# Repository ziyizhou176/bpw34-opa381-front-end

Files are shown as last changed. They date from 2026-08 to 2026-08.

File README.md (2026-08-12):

# BPW34 + OPA381 Weak-Signal Photodetector Front-End

KiCad-based, version-controlled redesign of a weak optical signal front-end for physics competition work.

## Final V2 design target

- Photodiode: BPW34
- TIA: OPA381
- Supply input: +5 V
- Analog rail: LP5907-3.3 -> AVDD_3V3
- Reference: REF3312 -> VREF_RAW -> 10 kΩ -> VBIAS_1V25, with local 1 µF bypass
- TIA feedback: 1 MΩ || 15 pF
- ADC isolation/filter: 1 kΩ series + 33 nF to AGND
- Calibration injection: CAL_IN -> 100 MΩ -> normally-open SJCAL -> SUM
- MCU interface: +5V_IN / AGND / ADC_OUT to existing STM32G431 board
- Target modulation/detection: 1 kHz optical modulation, 20 kS/s ADC, digital lock-in / FFT in MCU

## Development policy

This repository replaces GUI-only iterative PCB editing. Every electrical/layout milestone must be committed so that schematic, PCB, and production data can be diffed and rolled back.

Planned milestones:

1. `v0.1-schematic` — clean KiCad schematic, ERC pass, footprint mapping reviewed
2. `v0.2-placement` — critical analog placement frozen
3. `v0.3-critical-routing` — SUM, feedback, VBIAS, OPA381 local decoupling completed
4. `v0.4-full-routing` — remaining power/ADC/CAL routing and ground strategy completed
5. `v1.0-production` — DRC pass, Gerber/BOM/PnP ready for fabrication

## Reference design

Layout principles will be compared against the open hardware project `TU-Darmstadt-APQ/PDH_photodiode`, especially its photodiode/TIA placement, feedback-loop minimization, local decoupling, and ground strategy. The final circuit here is not intended to be an electrical clone; it is redesigned around BPW34, OPA381, 3.3 V single-supply operation, 1.25 V bias, STM32 ADC interfacing, and the calibration network used in this project.

## Status

Repository initialized. Next step: freeze the V2 electrical specification and create the KiCad project skeleton before any PCB routing.

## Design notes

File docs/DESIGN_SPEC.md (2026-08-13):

# Final V2 Electrical Design Specification

This document is the frozen electrical baseline for the KiCad redesign. PCB layout must conform to this specification unless a later commit explicitly changes it.

## 1. System purpose

Weak optical signal measurement front-end for an STM32G431-based instrument. The optical source is expected to be modulated at 1 kHz; the MCU samples at 20 kS/s and performs digital phase-sensitive/FFT processing.

## 2. External interface

### J1 — MCU / supply interface

| Pin | Net | Function |
|---|---|---|
| 1 | +5V_IN | Raw +5 V input |
| 2 | AGND | Analog ground |
| 3 | ADC_OUT | Analog output to STM32 ADC |

### J2 — calibration input

| Pin | Net | Function |
|---|---|---|
| 1 | CAL_IN | External calibration voltage |
| 2 | AGND | Calibration return |

### Production connector freeze

- J1: JST `S3B-PH-SM4-TB(LF)(SN)`, LCSC `C265101`, 3-pin PH 2.0 mm, right-angle SMD.
- J2: JST `S2B-PH-SM4-TB(LF)(SN)`, LCSC `C295747`, 2-pin PH 2.0 mm, right-angle SMD.
- Both connectors are side-entry/right-angle; their mating sides must face the outside of the PCB.
- Placement must follow the Pin 1 / circuit-number marker. Do not describe pin order using only “left” or “right”.
- Minimum courtyard is approximately 11.2 mm x 10.2 mm for J1 and 9.2 mm x 10.2 mm for J2.

## 3. Power chain

- `+5V_IN -> FB1 -> +5V_FILTER`
- `FB1 = BLM18AG601SN1D`, 600 Ω @ 100 MHz
- `U1 = LP5907MFX-3.3/NOPB`
- U1 pin mapping:
  - Pin 1 IN -> +5V_FILTER
  - Pin 2 GND -> AGND
  - Pin 3 EN -> +5V_FILTER
  - Pin 4 NC
  - Pin 5 OUT -> AVDD_3V3

Decoupling:

- C1 = 4.7 µF, +5V_IN to AGND
- C2 = 100 nF, +5V_IN to AGND
- C3 = 4.7 µF, +5V_FILTER to AGND
- C4 = 100 nF, +5V_FILTER to AGND
- C5 = 4.7 µF, AVDD_3V3 to AGND
- C6 = 100 nF, AVDD_3V3 to AGND

## 4. Reference and bias

- `U2 = REF3312AIDBZR`
- U2 pin mapping:
  - Pin 1 IN -> AVDD_3V3
  - Pin 2 OUT -> VREF_RAW
  - Pin 3 GND -> AGND
- C7 = 100 nF, AVDD_3V3 to AGND
- C8 = 1 µF, VREF_RAW to AGND
- R1 = 10 kΩ, 0.1%, `VREF_RAW -> VBIAS_1V25`
- C9 = 1 µF, `VBIAS_1V25 -> AGND`

Nominal bias target: approximately 1.25 V.

## 5. Photodiode and TIA

### D1 — BPW34

- Pin 1 / Anode -> AGND
- Pin 2 / Cathode -> SUM

### U3 — OPA381AIDGKR

Pin mapping:

| Pin | Function | Net |
|---|---|---|
| 1 | NC | NC |
| 2 | -IN | SUM |
| 3 | +IN | VBIAS_1V25 |
| 4 | V- | AGND |
| 5 | NC | NC |
| 6 | OUT | TIA_OUT |
| 7 | V+ | AVDD_3V3 |
| 8 | NC | NC |

Local decoupling:

- C10 = 100 nF, AVDD_3V3 to AGND, placed immediately adjacent to U3 supply pins
- C11 = 1 µF, AVDD_3V3 to AGND, local bulk decoupling

Feedback:

- RF1 = 1 MΩ, 0.1%, SUM to TIA_OUT
- CF1 = 15 pF, C0G, SUM to TIA_OUT
- Exactly one feedback branch; no gain-switch network on the Final V2 board

## 6. ADC output filter

- R2 = 1 kΩ, 0.1%, `TIA_OUT -> ADC_OUT`
- C12 = 33 nF, `ADC_OUT -> AGND`
- Target RC corner is approximately 4.8 kHz

## 7. Calibration network

- KiCad implementation reference mapping:
  - Functional name RCAL -> KiCad reference R3. R3 remains the 100 MΩ calibration resistor.
  - Functional name SJCAL -> KiCad reference SJ1. SJ1 remains the normally-open SJCAL jumper.
  - Functional name TP_CAL -> KiCad reference TP10. TP10 remains the CAL_IN calibration test point.
  - PCB silkscreen may retain the functional labels `SJCAL`, `OPEN`, and `TP_CAL`.
- TP_CAL -> CAL_IN
- RCAL = 100 MΩ, 1%, `CAL_IN -> CAL_R_NODE`
- SJCAL normally open:
  - Pad 1 -> CAL_R_NODE
  - Pad 2 -> SUM
- When SJCAL is closed:
  - `I_CAL = (V_CAL - VBIAS) / RCAL`
- CAL_IN and RCAL must remain electrically isolated from SUM while SJCAL is open

## 8. Test points

| Ref | Net | Nominal pad size |
|---|---|---|
| TP1 | +5V_IN | 1.0 mm |
| TP2 | +5V_FILTER | 1.0 mm |
| TP3 | AVDD_3V3 | 1.0 mm |
| TP4 | VREF_RAW | 1.0 mm |
| TP5 | VBIAS_1V25 | 1.0 mm |
| TP6 | SUM | 0.8 mm |
| TP7 | TIA_OUT | 1.2 mm |
| TP8 | ADC_OUT | 1.2 mm |
| TP9 | AGND | 1.2 mm |
| TP_CAL | CAL_IN | 1.0 mm |

TP6 silkscreen: `SUM_HIZ`.

## 9. PCB constraints

- 2 layers
- 45 mm x 30 mm nominal board size
- 1.6 mm FR-4
- 1 oz copper
- SUM is the highest-priority sensitive node
- D1, U3, RF1 and CF1 form one compact analog cluster
- Minimize SUM copper area and parasitic capacitance
- Keep ADC_OUT, CAL_IN and long AGND current paths away from SUM
- RF1 and CF1 must be physically adjacent to U3
- C10 must form the smallest practical U3 supply-decoupling loop
- Bottom layer should preferably provide a continuous AGND reference plane except where intentionally excluded around the SUM high-impedance region
- VBIAS guard geometry may be used around SUM if it can be implemented without increasing SUM capacitance or compromising routing

## 10. Production intent

Target fabrication/assembly route: JLCPCB / JLCEDA-compatible manufacturing output derived from KiCad Gerber, drill, BOM and pick-and-place files.

## 11. Reference-project policy

The TU Darmstadt `PDH_photodiode` project is used only as an engineering/layout reference. Its wideband ±5 V circuit, different photodiode, amplifier and gain are not copied electrically. Final V2 remains a 3.3 V single-supply OPA381/BPW34 design described by this specification.

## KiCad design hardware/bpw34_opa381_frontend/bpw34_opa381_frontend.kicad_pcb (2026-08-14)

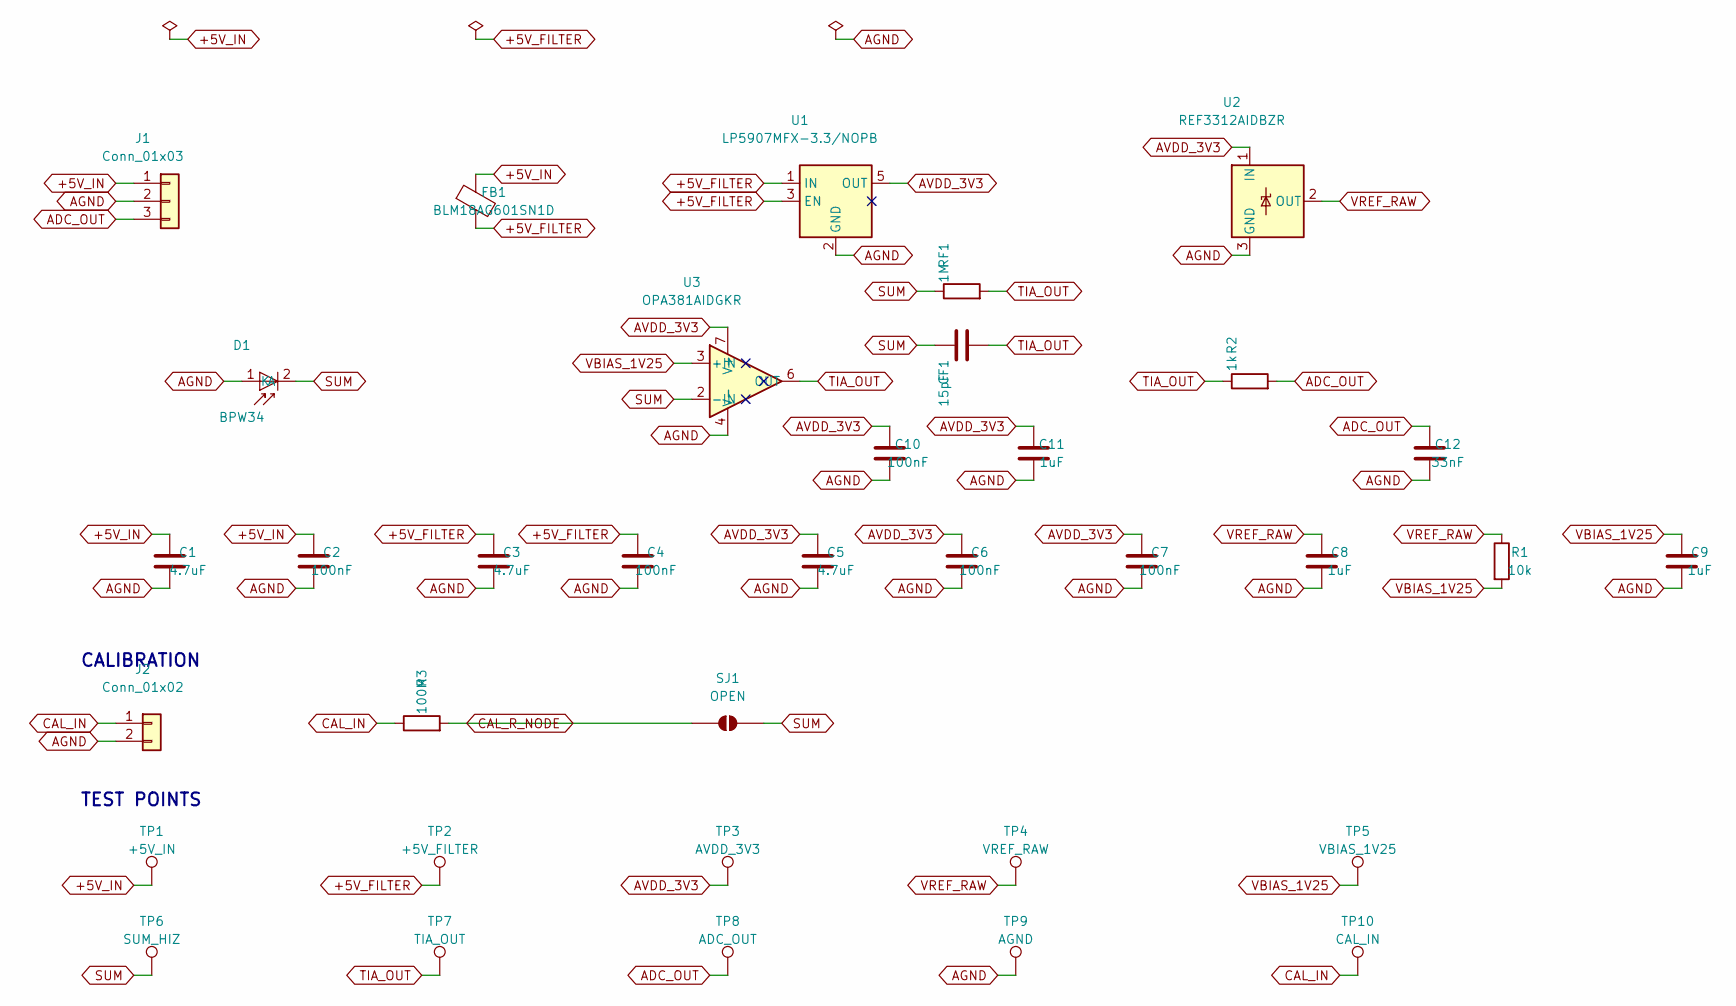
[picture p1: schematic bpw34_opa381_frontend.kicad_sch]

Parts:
C1, C3, C5: 4.7uF; C_0603_1608Metric; MPN GRM188Z71C475KE21D; LCSC C389010
C2, C4, C6, C7, C10: 100nF; C_0603_1608Metric; MPN CL10B104KO8NNNC; LCSC C66501
C8, C9, C11: 1uF; C_0603_1608Metric; MPN 0603B105K160CT; LCSC C108463
C12: 33nF; C_0603_1608Metric; MPN CL10B333KB8NNNC; LCSC C21117
CF1: 15pF; C_0603_1608Metric; MPN CL10C150JB8NNNC; LCSC C1644
D1: BPW34; BPW34_Vishay_P5.10mm; MPN BPW34; LCSC C85128
FB1: BLM18AG601SN1D; L_0603_1608Metric; MPN BLM18AG601SN1D; LCSC C19330
J1: Conn_01x03; JST_PH_S3B-PH-SM4-TB_1x03-1MP_P2.00mm_Horizontal; MPN S3B-PH-SM4-TB(LF)(SN); LCSC C265101
J2: Conn_01x02; JST_PH_S2B-PH-SM4-TB_1x02-1MP_P2.00mm_Horizontal; MPN S2B-PH-SM4-TB(LF)(SN); LCSC C295747
R1: 10k; R_0603_1608Metric; Tolerance 0.1%; MPN RT0603BRD0710KL; LCSC C95204
R2: 1k; R_1206_3216Metric; Tolerance 0.1%; MPN RT1206BRD071KL; LCSC C706405
R3: 100M; R_1206_3216Metric; Tolerance 1%; MPN 1206W4F1006T5E; LCSC C59781
RF1: 1M; R_1206_3216Metric; Tolerance 0.1%; MPN RT1206BRD071ML; LCSC C309662
SJ1: OPEN; SolderJumper-2_P1.3mm_Open_RoundedPad1.0x1.5mm
TP1: +5V_IN; TestPoint_Pad_D1.0mm
TP2: +5V_FILTER; TestPoint_Pad_D1.0mm
TP3: AVDD_3V3; TestPoint_Pad_D1.0mm
TP4: VREF_RAW; TestPoint_Pad_D1.0mm
TP5: VBIAS_1V25; TestPoint_Pad_D1.0mm
TP6: SUM_HIZ; TestPoint_Pad_D0.8mm
TP7: TIA_OUT; TestPoint_Pad_D1.2mm
TP8: ADC_OUT; TestPoint_Pad_D1.2mm
TP9: AGND; TestPoint_Pad_D1.2mm
TP10: CAL_IN; TestPoint_Pad_D1.0mm
U1: LP5907MFX-3.3/NOPB; SOT-23-5; MPN LP5907MFX-3.3/NOPB; LCSC C80670
U2: REF3312AIDBZR; SOT-23; MPN REF3312AIDBZR; LCSC C183104
U3: OPA381AIDGKR; VSSOP-8_3x3mm_P0.65mm; MPN OPA381AIDGKR; LCSC C2870973

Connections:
+5V_FILTER: C3.1, C4.1, FB1.2, TP2.1, U1.1 (IN), U1.3 (EN)
+5V_IN: C1.1, C2.1, FB1.1, J1.1, TP1.1
ADC_OUT: C12.2, J1.3, R2.2, TP8.1
AGND: C1.2, C2.2, C3.2, C4.2, C5.2, C6.2, C7.2, C8.2, C9.2, C10.1, C11.1, C12.1, D1.1 (A), J1.2, J2.2, TP9.1, U1.2 (GND), U2.3 (GND), U3.4 (V-)
AVDD_3V3: C5.1, C6.1, C7.1, C10.2, C11.2, TP3.1, U1.5 (OUT), U2.1 (IN), U3.7 (V+)
CAL_IN: J2.1, R3.1, TP10.1
CAL_R_NODE: R3.2, SJ1.1 (A)
SUM: CF1.1, D1.2 (K), RF1.1, SJ1.2 (B), TP6.1, U3.2 (-IN)
TIA_OUT: CF1.2, R2.1, RF1.2, TP7.1, U3.6 (OUT)
VBIAS_1V25: C9.1, R1.2, TP5.1, U3.3 (+IN)
VREF_RAW: C8.1, R1.1, TP4.1, U2.2 (OUT)

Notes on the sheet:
CALIBRATION
TEST POINTS

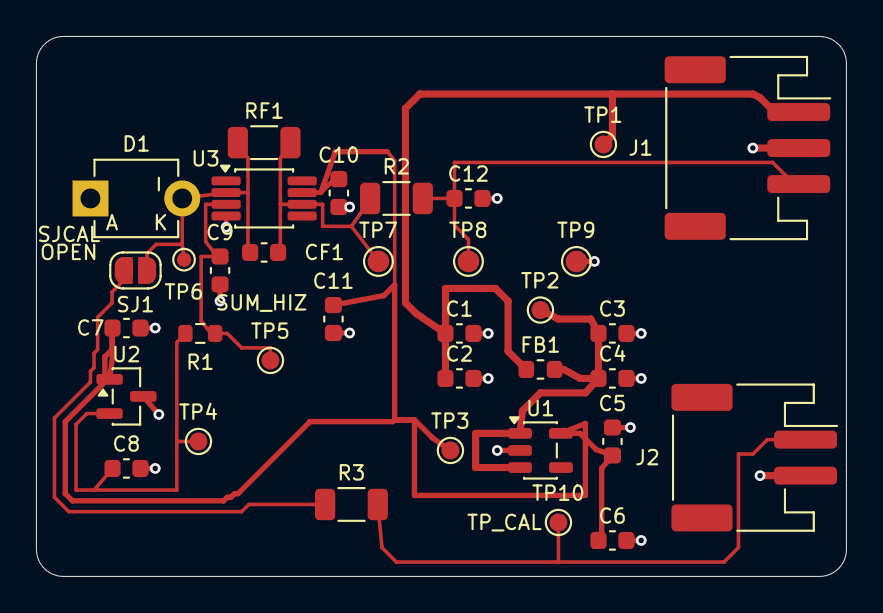
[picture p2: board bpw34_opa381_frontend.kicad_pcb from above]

Board: 2 copper layers, 45.0 x 30.0 mm, 35 parts (0 on the bottom side), 11 nets.

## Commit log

2026-08-12 Initialize KiCad Final V2 repository
2026-08-12 Add KiCad gitignore rules
2026-08-12 Initialize KiCad project skeleton
    [bpw34_opa381_frontend.kicad_pcb, bpw34_opa381_frontend.kicad_sch]
2026-08-13 Add project-specific KiCad libraries
2026-08-13 Add v0.1-A power and reference schematic
    [bpw34_opa381_frontend.kicad_sch]
2026-08-13 Add v0.1-B TIA and ADC filter schematic
    [bpw34_opa381_frontend.kicad_sch]
2026-08-13 Add project test-point footprints
2026-08-13 Complete v0.1 schematic with calibration and test points
    [bpw34_opa381_frontend.kicad_sch]
2026-08-13 Freeze J1 and J2 production connectors
    [bpw34_opa381_frontend.kicad_sch]
2026-08-13 Complete v0.2 PCB placement and DRC setup
    [bpw34_opa381_frontend.kicad_pcb]
2026-08-14 Complete v0.3 critical analog routing
    [bpw34_opa381_frontend.kicad_pcb]
2026-08-14 Complete v0.4 final PCB routing
    [bpw34_opa381_frontend.kicad_pcb]
